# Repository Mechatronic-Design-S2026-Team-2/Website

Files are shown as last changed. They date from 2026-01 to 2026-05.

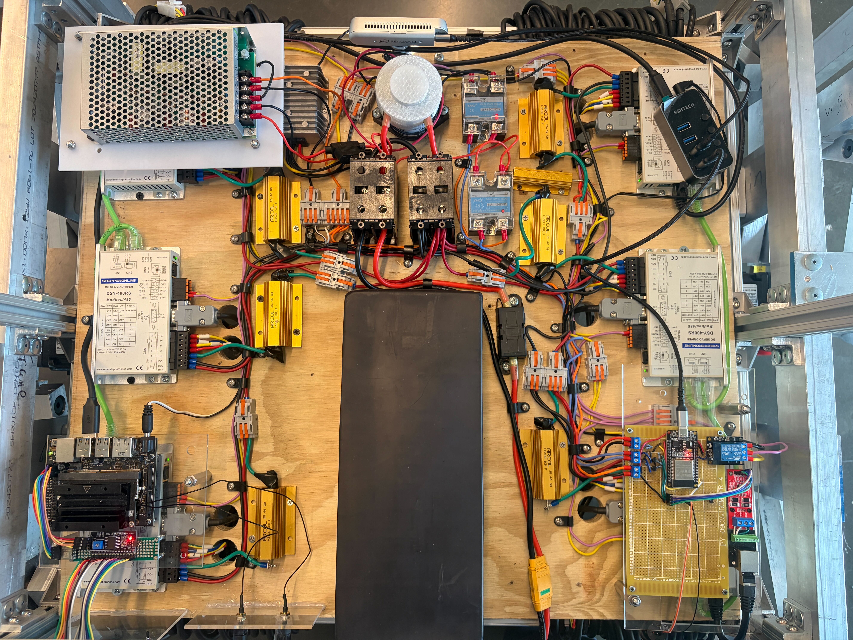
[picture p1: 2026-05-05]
docs/assets/hardware/full_circuit_mainboard.jpg

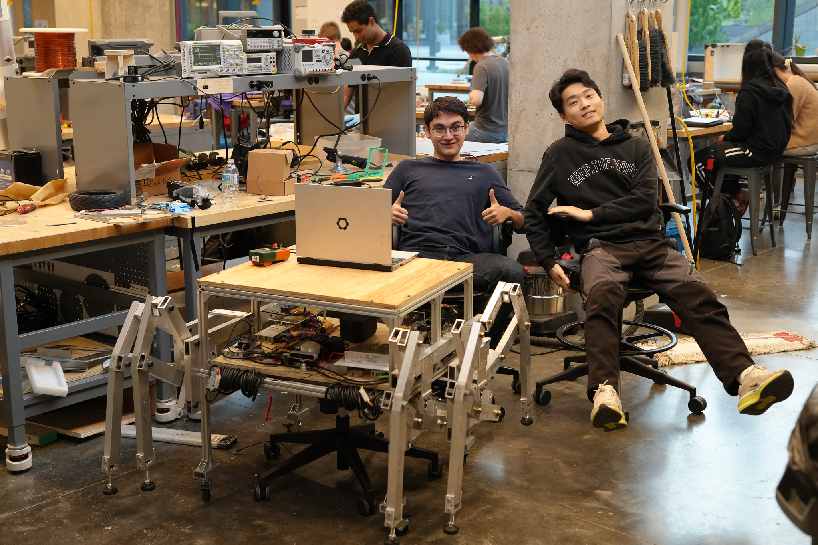
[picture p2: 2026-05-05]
docs/assets/hardware/working_on_bot.jpg

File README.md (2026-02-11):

# Team 2 — Dance Robot Project Website 

This repo is a **GitHub Pages** site for the Mechatronic Design project website.

## What’s included
- Required top-level pages: Problem, Design, Implementation, Performance, Management, Media, Team, Documents
- A Documents “workbook” area with folders for brainstorming, schematics, testing, software, presentations, ILRs
- Project management templates: schedule, parts list, issues log (CSV)

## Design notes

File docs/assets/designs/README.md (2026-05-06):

# CAD and design exports

Existing GLB files are used by the site. Add final exports here:

- klann_final.glb
- v5_final_assembly.glb
- linkage_schematic.pdf

The linkage drawing should be exported as PDF for browser-friendly viewing and downloading. Keep the original DWG in the repo as a source file if useful, but the website now references the PDF.

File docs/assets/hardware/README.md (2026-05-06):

# Hardware photos

Place final hardware, cover, chassis/electronics, and electrical integration photos here:

- full_circuit_mainboard.jpg
- full_assembly_no_lid.jpg
- chassis_and_early_board.jpg
- front_final_cover.JPG
- angled_final_cover.JPG
- mainboard_in_progress.jpg
- pcb_mount_prototype.jpg
- working_on_bot.jpg
- debugging.jpg

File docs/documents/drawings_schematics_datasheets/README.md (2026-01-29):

[Home](index.md) •
[Problem](problem.md) •
[Design](design.md) •
[Implementation](implementation.md) •
[Performance](performance.md) •
[Project Management](management.md) •
[Media](media.md) •
[Documents](documents.md) •
[Team](team.md)

# Drawings / Schematics / Datasheets

Store PDFs/images of CAD, wiring diagrams, schematics, and relevant datasheet excerpts.

## Suggested structure
- `YYYY-MM-DD_<short_title>.pdf` or `.md`
- Keep files small; link to external storage for huge videos/logs.

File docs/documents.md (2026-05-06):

---
title: "Documents (Workbook)"
---

{% include nav.html %}
{% include page-assets.html cards=true %}

<div class="t2-card">
  <h2>Documents</h2>
  <p>
    Core reports and presentations are embedded here so the website can serve as a self-contained project workbook. The final report is the most accurate source for the as-built mechanical/electrical design and budget. The mapping report is the most detailed source for the Jetson/ESP32/RS485/kinematic-odometry software stack.
  </p>
</div>

{% include pdf-card.html
   title="Final Report"
   pdf="/assets/pdfs/final_report.pdf"
   subtitle="As-built class-final report: final design, system evaluation, budget, risks, and future work."
   height="82vh" %}

{% include pdf-card.html
   title="Resource-Constrained Odometry, Localization, and Mapping Report"
   pdf="/assets/pdfs/mapping_report.pdf"
   subtitle="Detailed software paper covering raw encoder timing, Klann kinematic odometry, ORB-SLAM2 CUDA, slam_toolbox, Nav2, and fusion."
   height="82vh" %}

{% include pdf-card.html
   title="Mapping Proposal"
   pdf="/assets/pdfs/Mapping_proposal.pdf"
   subtitle="Original staged plan for onboard odometry, localization, mapping, and embedded feasibility evaluation."
   height="72vh" %}

{% include pdf-card.html
   title="Design Proposal"
   pdf="/assets/pdfs/design-proposal.pdf"
   subtitle="Initial mechanical/electrical/software design proposal, retained for design history and trade-study context."
   height="72vh" %}

{% include pdf-card.html
   title="Design Proposal Presentation"
   pdf="/assets/pdfs/design-proposal-presentation.pdf"
   subtitle="Proposal slide deck."
   height="72vh" %}

{% include pdf-card.html
   title="Mapping Presentation"
   pdf="/assets/pdfs/mapping_presentation.pdf"
   subtitle="Localization and mapping presentation deck."
   height="72vh" %}

{% include pdf-card.html
   title="Midsemester Presentation"
   pdf="/assets/pdfs/midsemester_presentation.pdf"
   subtitle="Midsemester status and design evolution."
   height="72vh" %}

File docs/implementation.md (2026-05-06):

---
title: "System Implementation"
---

{% include nav.html %}
{% include page-assets.html cards=true implementation=true media_gallery=true model_viewer=true svg_diagram=true carousel=true %}

<div class="t2-card" id="implementation-status">
  <h2>Implementation</h2>
  <p class="t2-sub">As-built hardware, firmware, Jetson deployment, ROS 2 package integration, and operator workflow for the class-final robot.</p>
  <p>
    The final robot is a distributed system with one ESP32 responsible for power sequencing and motor-bus I/O, a Jetson Nano host responsible for the RealSense/ORB-SLAM2 CUDA process, and a ROS 2 Jazzy container responsible for state estimation, visualization, mapping, navigation, operator controls, and micro-ROS integration.
  </p>
  <div class="t2-links">
    <a class="t2-linkbtn" href="#hardware-build">Hardware build</a>
    <a class="t2-linkbtn" href="#firmware-runtime">ESP32 runtime</a>
    <a class="t2-linkbtn" href="#jetson-deployment">Jetson deployment</a>
    <a class="t2-linkbtn" href="#ros-packages">ROS 2 packages</a>
    <a class="t2-linkbtn" href="#integration-flow">Integration flow</a>
    <a class="t2-linkbtn" href="#operatorui">Operator UI</a>
  </div>
</div>

<div class="t2-card" id="hardware-build">
  <h2>Hardware Build</h2>
  <p>
    The build sequence progressed from raw aluminum stock through chassis fabrication, linkage fabrication, electronics mounting, and final assembly. The ordered carousel shows the manufacturing path rather than isolated hero photos, making the final hardware easier to relate to the design evolution and budget.
  </p>
  {% include carousel.html key="hardware_build_sequence" %}
</div>

<div class="t2-card" id="firmware-runtime">
  <h2>ESP32 Firmware Runtime</h2>
  <p>
    The ESP-IDF firmware keeps startup and runtime deliberately separate. Startup uses the slower, proven configuration path for precharge, contactor closure, servo enable, motor mode setup, torque/current limiting, speed limits, acceleration/deceleration settings, and initial zero-speed commands. Runtime then switches to short RS485 helpers for changed RPM writes and encoder reads.
  </p>
  {% include carousel.html key="esp_runtime_sequence" %}
  <div class="t2-table-wrap">
    <table class="t2-table">
      <thead><tr><th>Runtime feature</th><th>Final behavior</th><th>Reason</th></tr></thead>
      <tbody>
        <tr><td>RPM command writes</td><td>Changed-only writes by default; stop commands can preempt between RS485 transactions.</td><td>Avoids wasting the 115200 baud bus rewriting unchanged speeds.</td></tr>
        <tr><td>Encoder telemetry</td><td>Strict six-drive raw encoder sweep, then compact micro-ROS odometry publication.</td><td>Keeps all legs observable and avoids odd/even polling starvation.</td></tr>
        <tr><td>Phase semantics</td><td>ESP publishes raw 17-bit single-turn encoder counts rather than final output phase.</td><td>The 50:1 gearbox causes many motor-encoder wraps per crank revolution, so continuous phase belongs on the Jetson observer.</td></tr>
        <tr><td>Timing fields</td><td>Command sequence, receive, apply, poll, and publish timestamps are included.</td><td>Host-side estimation can reason about command propagation and measurement age.</td></tr>
      </tbody>
    </table>
  </div>
  <p class="t2-note">
    Final deployed runtime parameters from the mapping report include RS485 motor bus at 115200 baud, micro-ROS UART at 921600 baud, one runtime transaction attempt, a 25 ms six-drive encoder sweep target, a 50 ms odometry publish period, 131072 encoder counts per motor revolution, 50:1 gearbox ratio, and 250 ms / 250 ms motor driver acceleration/deceleration settings.
  </p>
</div>

<div class="t2-card" id="jetson-deployment">
  <h2>Jetson Deployment</h2>
  <p>
    The Jetson Nano deployment is split because the project needs both host-native GPU/RealSense access and a modern ROS 2 stack. ORB-SLAM2 CUDA, RealSense, CUDA/OpenCV, and Pangolin run directly on the Jetson host. ROS 2 Jazzy runs in a Docker container with host networking and the project workspace mounted for development.
  </p>
  {% include carousel.html key="jetson_deployment_sequence" %}
  <details class="t2-acc" open>
    <summary><h3>Host-native process</h3></summary>
    <div class="t2-acc-body">
      <p>
        The RealSense executable acquires aligned RGB-D frames from the D415, uses meter-scale depth, skips malformed frames, hardens startup/retry behavior, and emits UDP products to <code>127.0.0.1:5005</code> for the ROS container.
      </p>
    </div>
  </details>
  <details class="t2-acc">
    <summary><h3>Container role</h3></summary>
    <div class="t2-acc-body">
      <p>
        The container runs the hardware observers, Klann geometry model, weighted odometry fusion, ORB UDP bridge, slam_toolbox, Nav2, RViz, operator interface, and micro-ROS agent integration. Host networking keeps UDP, TF, and ROS discovery simple on the robot.
      </p>
    </div>
  </details>
</div>

<div class="t2-card" id="ros-packages">
  <h2>ROS 2 Packages</h2>
  <p>
    The ROS workspace is organized so low-level messages stay compact and high-level nodes reconstruct the robot state before planners see it.
  </p>
  <div class="t2-table-wrap">
    <table class="t2-table">
      <thead><tr><th>Package</th><th>Implemented role</th><th>Representative topics / outputs</th></tr></thead>
      <tbody>
        <tr><td><code>dsy_motor_msgs</code></td><td>ESP bridge messages for motor RPM command and six-drive raw encoder/timing telemetry.</td><td><code>/motor_rpm_cmd</code>, <code>/motor_output_odom</code></td></tr>
        <tr><td><code>hexapod_control_interfaces</code></td><td>Robot-level leg phase, motor state, actuation, and body-state messages.</td><td><code>/hexapod/phase_cmd</code>, <code>/hexapod/motor_state</code>, <code>/hexapod/body_state</code></td></tr>
        <tr><td><code>hexapod_hardware_cpp</code></td><td>Motor-state aggregation, encoder unwrap, measured Klann model, body-kinematic odometry, weighted fusion, WT901 interface, startup pose, LCD/status, and RViz markers.</td><td><code>/hexapod/kinematic_odom</code>, <code>/hexapod/fused_odom</code>, <code>/odom</code>, <code>/klann_markers</code></td></tr>
        <tr><td><code>hexapod_nav_cpp</code></td><td>Planner-facing phase prediction and phase command generation, including final phase wrapping and mirror/direction correction.</td><td>Phase targets bounded to <code>[-pi, pi]</code></td></tr>
        <tr><td><code>hexapod_orbslam_udp_bridge</code></td><td>UDP bridge from host-native ORB-SLAM2 CUDA to ROS odometry, sparse points, and depth-derived virtual scan.</td><td><code>/hexapod/orbslam_odom</code>, <code>/orbslam/map_points</code>, <code>/scan</code></td></tr>
        <tr><td><code>hexapod_operator_interface</code></td><td>Browser GUI for teleop, map viewing, waypoint goals, velocity limits, map save/load, and software e-stop.</td><td><code>/hexapod/cmd_vel_selected</code>, Nav2 goals, map service calls</td></tr>
      </tbody>
    </table>
  </div>
</div>

<div class="t2-card" id="integration-flow">
  <h2>Integration Flow</h2>
  <p>
    Final bring-up combines power sequencing, encoder telemetry, host SLAM, ROS 2 mapping/control, and operator commands in a repeatable order.
  </p>
  {% include carousel.html key="integration_flow_sequence" %}
  <ol>
    <li>Precharge the 52 V bus, close the contactor, and enable the servo drivers only after voltage and timing checks pass.</li>
    <li>Validate RS485 command writes and six-drive raw encoder telemetry before commanding gait motion.</li>
    <li>Start the host-native ORB-SLAM2 CUDA/RealSense process and confirm UDP pose, points, and virtual scan output.</li>
    <li>Launch the ROS 2 container stack, verify TF/scale alignment in RViz, then enable teleop or waypoint control.</li>
  </ol>
</div>

<div class="t2-card" id="operatorui">
  <h2>Operator Interface</h2>
  <p>
    The operator interface is a browser page served from the ROS 2 side of the Jetson. It exposes teleop, velocity limits, map visualization, waypoint placement, map save/load, status display, and a software stop mode so testing can be performed without manually invoking every ROS command.
  </p>
  <p>
    The final workflow keeps the laptop as a remote terminal and visualization/control client while the robot carries the Jetson, ESP32, battery, motor drivers, and sensors onboard.
  </p>
</div>

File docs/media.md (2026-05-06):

---
title: "Media"
---

{% include nav.html %}
{% include page-assets.html cards=true media_gallery=true model_viewer=true %}

<div class="t2-card">
  <h2>Media</h2>
  <p>
    This page collects final build, fabrication, electrical integration, software visualization, simulation verification, CAD/modeling, and robot-motion media. WebM clips are presented as silent looping animations; the single-linkage MP4 is also rendered as an inline looping mechanism animation.
  </p>
  
</div>

<div class="t2-card">
  {% include asset-gallery.html key="team_picture" %}
</div>

<div class="t2-card">
  {% include asset-gallery.html key="build_photos" %}
</div>

<div class="t2-card">
  {% include asset-gallery.html key="fabrication" %}
</div>

<div class="t2-card">
  {% include asset-gallery.html key="circuit_photos" %}
</div>

<div class="t2-card">
  {% include asset-gallery.html key="software_visuals" %}
</div>

<div class="t2-card">
  {% include asset-gallery.html key="simulation_media" %}
</div>

<div class="t2-card">
  {% include asset-gallery.html key="videos" %}
</div>

<div class="t2-card">
  <h2>Fusion 360 CAD Embeds and Local Fallbacks</h2>
  <p>
    Fusion 360 embeds are the primary detailed CAD views for the schematic, final assembly, final Klann linkage, and later assembly iterations. Each card also exposes the local PDF or GLB fallback so the site still has a usable static artifact if Autodesk sharing is unavailable. Version 1 remains a local GLB viewer because no Fusion embed is configured for it.
  </p>
  <p class="t2-note">
    To force a local fallback, set <code>use_fallback: true</code> on that item in <code>docs/_data/media_assets.yml</code>. Leave it <code>false</code> to use the Fusion 360 iframe by default.
  </p>
  {% include asset-gallery.html key="fusion_cad" %}
</div>

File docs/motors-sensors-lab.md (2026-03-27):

---
title: "Motors/Sensors Lab"
---

{% include nav.html %}
{% include page-assets.html cards=true carousel=true lab=true codebox=true %}

<div class="t2-card">
  <h2>Lab highlights</h2>

  {% include lab-carousel.html %}
</div>

<div class="t2-card">
  <h2>KiCad schematic</h2>
  {% include kicad-embed.html
     wrap="false"
     repo="Mechatronic-Design-S2026-Team-2/Website"
     ref="main"
     path="docs/assets/designs/sensor_motor_lab/18578sensor.kicad_sch"
  %}
</div>

<div class="t2-card">
  <h2>Mainfile</h2>

  {% include repo-button.html
   label="Sensors/Motors Lab repo"
   href="https://github.com/Mechatronic-Design-S2026-Team-2/Sensors-Motors-Lab" %}

  {% include lab-code.html wrap="false" %}
</div>

<div class="t2-card" id="ilrs">
  <h2>ILRs</h2>
  <div class="t2-sub">In-lab reports (PDFs). Expand each dropdown to view.</div>

  {% include ilr-dropdowns.html %}
</div>

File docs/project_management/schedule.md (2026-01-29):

[Home](index.md) •
[Problem](problem.md) •
[Design](design.md) •
[Implementation](implementation.md) •
[Performance](performance.md) •
[Project Management](management.md) •
[Media](media.md) •
[Documents](documents.md) •
[Team](team.md)

# Schedule (Template)

Add your Gantt chart image here **or** maintain milestones below.

## Milestones
- Week X: Locomotion prototype v1
- Week X: Sensor bring-up (camera/IMU/encoders)
- Week X: Basic state estimation
- Week X: Point-to-point navigation demo
- Week X: Obstacle stop behavior
- Week X: Full system integration + performance testing

## Weekly plan
| Week | Focus | Owner(s) | Deliverable |
|---|---|---|---|
| 1 | Setup repo + website + bring-up | TBD | Site live + dev environment |
| 2 | TBD | TBD | TBD |

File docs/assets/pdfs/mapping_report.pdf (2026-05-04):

## Resource-Constrained Odometry, Localization, and Mapping on a Human-Carrying Hexapod

Daniel González Lázaro

Abstract— This report summarizes the final implemented odometry, localization, and mapping stack for a human-carrying Klann-linkage hexapod built around a Jetson Nano, a RealSense D415, six RS485 servo motor drivers with 17-bit motor encoders, 50:1 planetary gearboxes, and an ESP32 micro-ROS bridge. telemetry, a ROS 2 C++ motor-state observer that unwraps single-turn 17-bit motor encoders through the 50:1 gearbox, a Klann-body kinematic odometry estimator, a planar weighted odometry fusion node, and an ORB-SLAM2 CUDA RealSense UDP bridge that exports pose, map points, and a lightweight virtual scan for slam_toolbox and Nav2 occupancy-grid navigation. The biggest embedded issues were not the high-level ROS interfaces, but the RS485 transaction schedule, the semantics of the servomotor encoder, and the limited reliability of the ESP32 ADC channels for foot-contact sensing. The final system produced teleoperated straight-line odometry results within the 6 tolerance required by the AXIS Dance Company collaboration, although the kinematic scale remains a tunable calibration parameter. The resulting architecture treats RGB-D SLAM as the primary mapping/localization source and treats body-kinematic odometry as a fallback and fusion component when visual tracking is degraded or the camera is partially occluded by riders or nearby people.

I. INTRODUCTION AND FINAL SYSTEM CONTEXT

The target platform is an assistive mobility device for AXIS Dance Company that must transport a rider without wheels as the primary locomotor, fit within a 5 ft by 5 ft footprint, carry up to a 170 lb rider while keeping the total mass of the system below 150 lb, and navigate to a designated point in a performance stage within 6 in in 1 min [1]. The final demonstrations also require straight and curvilinear forward and backward traversals over 10 feet in a test area of 10 feet by 10 feet, with penalties for path deviation and manual intervention [1]. These requirements make odometry and mapping central to the project rather than optional instrumentation.
The final implementation uses a staged estimator. The RealSense D415 and ORB-SLAM2 CUDA process provide exteroceptive motion and sparse mapping; the ROS 2 UDP bridge converts this output into ROS odometry, point-cloud visualization, and a virtual planar scan for slam_toolbox occupancy mapping. That occupancy grid is included for the Nav2 navigation stack, not merely for visualization: it is the grid map on which future autonomous goal selection,

This implementation was a component of Spring 2026 mechatronic design’s team 2, and our human-carrying hexapod project. Other members of team 2 are: Yechen Zheng, Hongfei Liu, and Hongru Liu
Project website: https://mechatronic-design-s2026-team-2.github.io/Website/. (https://mechatronic-design-s2026-team-2.github.io/Website/) Code repository: https://github.com/Mechatronic-Design-S2026-Team-2/Design. (https://github.com/Mechatronic-Design-S2026-Team-2/Design)

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

II. FINAL EMBEDDED MOTOR AND ENCODER
IMPLEMENTATION
The | final | ESP32 | firmware | accepts
dsy_motor_msgs/MotorRpmArray
on | /motor_rpm_cmd | and | publishes
dsy_motor_msgs/MotorOutputOdometryArray
on /motor_output_odom. The message package name is historical; the relevant hardware behavior is that one ESP32 controls six RS485 servo drives. The six-element command and odometry vectors remain in physical ESP bus order [rb, rm, rf, lf, lm, lb], which follows the physical wire distance from the ESP32 to the motor drivers on the RS485 daisy chain, from closest to farthest. On the host, this is remapped to the canonical kinematic model
order [rf, rm, rb, lf, lm, lb] through [2, 1,

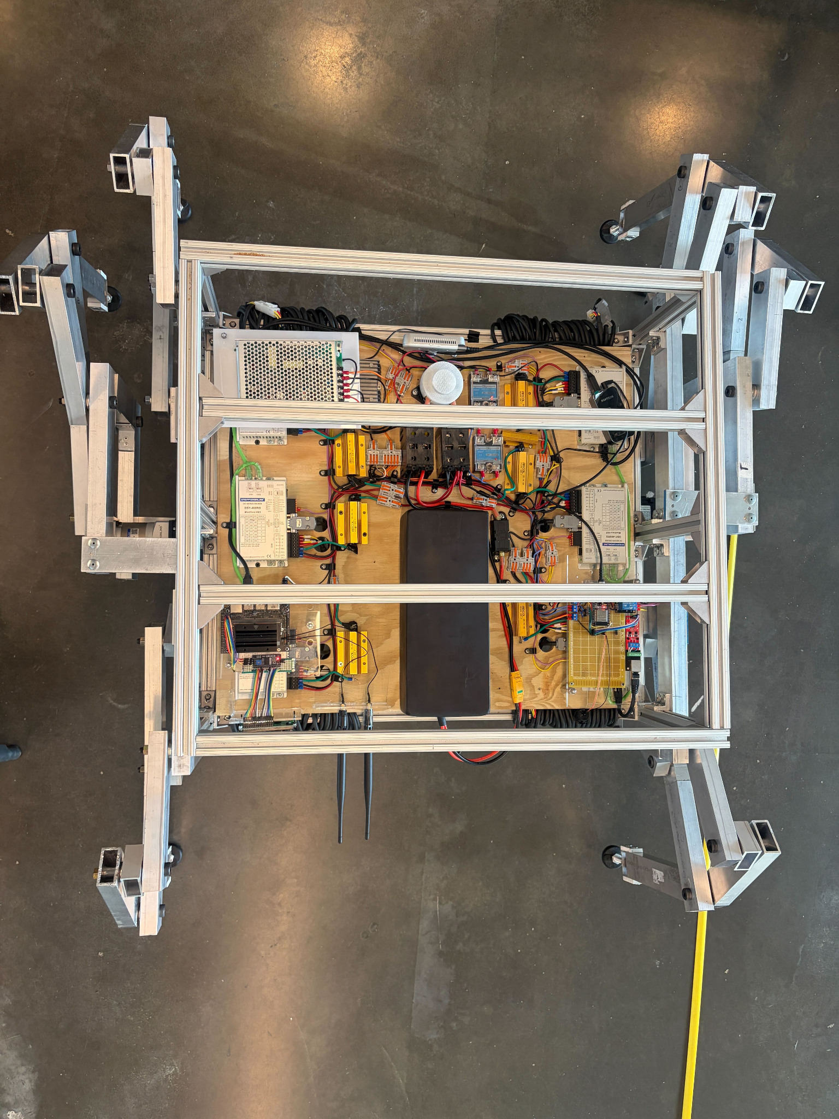
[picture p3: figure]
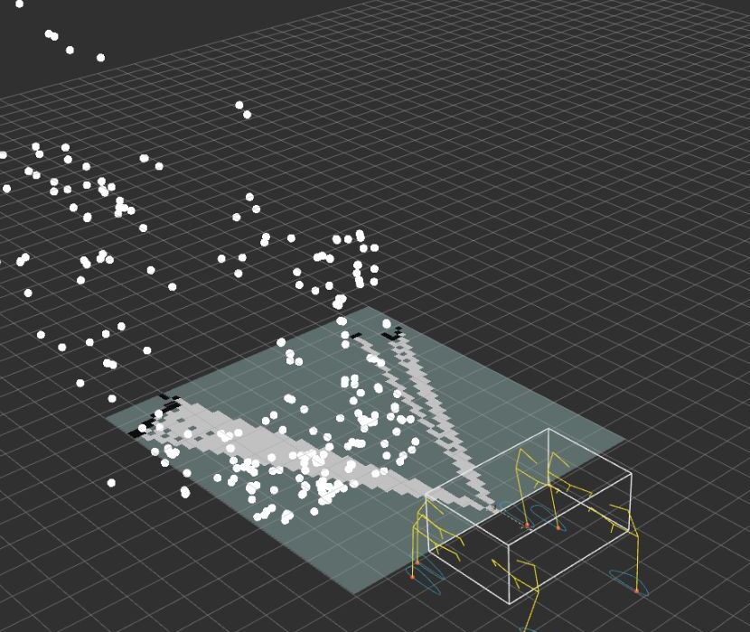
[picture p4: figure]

(a) final top-view hardware layout | (b) merged RViz view with skeleton, ORB points, and occupancy/grid products

Fig. 1. Final physical and mapping configuration. The top-view chassis photograph shows the distributed electronics, motor-driver layout, RS485 wiring context, and six linkage modules. The merged visualization shows the robot skeleton, sparse visual map products, and the grid/scan products used to validate scale and transform consistency before using the map for Nav2 navigation.

0, 3, 4, 5]. This separation was important because
bus-debugging tools, direct teleoperation tests, and firmware
logs are easiest to interpret in cable order, while the Klann model and controller need a consistent front/middle/back order for each side.

The final embedded code deliberately separates startup configuration from runtime communication. Startup retains the slower verified path for motor-driver configuration, including control mode, torque/current limiting, speed command source, speed limits, acceleration/deceleration parameters, and enable sequencing. Runtime uses short RS485 helpers for changed RPM writes and encoder reads. This reduced risk because earlier event-driven versions changed too much of the bringup code at the same time as the runtime path. Reusing the proven power/enable sequence also avoided failures where the active-low servo-enable relay briefly left the drives disabled or caused inconsistent drive readiness.

The runtime message includes timing fields added specifically for delay-aware host estimation: command_seq,
last_cmd_seq, | esp_cmd_rx_time_us,
esp_apply_complete_time_us,
esp_poll_complete_time_us, | and
esp_publish_time_us. | These | fields | allow | the
ROS 2 observer to estimate command receive-to-apply time, apply-to-poll time, poll-to-publish time, and the external transport delay between the host and ESP32. The estimator uses these values to compensate phase for measurement age

TABLE I

FINAL DEPLOYED RUNTIME PARAMETERS USED BY THE SOFTWARE

STACK.

Parameter | Final value
RS485 motor bus baud rate | 115200
micro-ROS UART baud rate | 921600
RS485 runtime response timeout | 50 ms
RS485 runtime turnaround delay | 2 ms
Runtime transaction attempts | 1
Six-drive encoder sweep period | 25 ms
Odometry publish period | 50 ms
Encoder counts per motor rev | 131072
Gearbox ratio | 50:1
Driver accel/decel time | 250 ms / 250 ms
Kinematic XY scale | 2.1786
ORB/scan scale | 1.382
Virtual scan range | 0.45–3.0 m
Camera X offset from base_link | 0.2794 m

and future command-application delay rather than treating every motor sample as instantaneous.
The motor command path uses changed-only writes by default. Once a drive has accepted a commanded RPM, that RPM is not resent unless the value changes or a periodic resend mode is explicitly enabled. This behavior matters on a six-drive 115200 baud bus. Continuously rewriting unchanged commands consumes the same bus capacity needed to poll encoders, and it can make the odometry stream appear frozen even though the micro-ROS topic itself is still publishing.
The key firmware change is that the ESP32 no longer attempts to compute output-shaft phase in the embedded runtime path. Instead, output_phase_rad[] is reused, for compatibility with the existing message definition, to carry raw P18.32/P18.33 single-turn encoder counts. For the installed M17S 17-bit encoders, the raw range is 0 to 131071 counts per motor revolution, which fits exactly in the float field used by the current message. The host computes continuous phase by unwrapping the modulo count, applying the 50:1 gearbox ratio, applying the physical-to-model sign convention, and subtracting the startup reference. This moved the ambiguous part of the estimate from the memory- and timing-constrained ESP32 into the ROS 2 observer, where command history and model constraints are available.
The code finally treats P18.32/P18.33 as a single-round absolute encoder value and leaves P18.34 out of the odometry path. Earlier debugging considered feedback pulse counters and multi-round monitor registers, but the reliable source for the installed M17S encoder was the modulo single-turn value. The RS485 driver also includes a word-order guard for this 32-bit monitor value: if the high-word-first interpretation is outside the expected 17-bit range but the low-word-first interpretation is valid, the valid ordering is selected. This avoids silently accepting a nonsensical encoder count caused by Modbus word-order differences.
For a raw count ck, counts per motor revolution N = 131072, and gearbox ratio G = 50, the host observer estimates output phase as

ϕk = si

2π
NGCˆ
k + ϕ0i
, | (1)

where si

is the physical-to-model sign for leg i, ϕ0i | is
the configured phase offset, and Cˆ
k is the continuous unwrapped motor-count estimate. The observer predicts Cˆ
| k
from the latest accepted command and the configured acceleration/deceleration time, then corrects it toward the raw encoder measurement by choosing the nearest plausible wrap. A bounded innovation prevents a single stale or misread RS485 sample from jumping the phase by multiple motor turns.
This design also makes explicit that the encoder is a single-turn motor encoder, not a multi-turn output encoder. A full output-shaft revolution corresponds to 50 motor revolutions, so the raw motor encoder wraps many times during one output cycle. The host can infer the correct wrap count only if the raw count is polled often enough that the count change between accepted samples remains below the half-revolution ambiguity limit, or if commanded RPM and acceleration constraints are used to choose the nearest plausible wrap. The final observer therefore combines raw-count measurements with a ramp-limited command prediction. It ignores unchanged raw samples during commanded motion when the ESP has merely republished a cached six-element vector while the RS485 worker has not yet refreshed that drive. The physical phase zero was set manually. Before tests, each linkage output crank was positioned to point straight down from the motor output shaft so that all six legs began from the same mechanical phase. In software, this corresponds to zero phase offsets in the deployed configuration. This manual setup made phase visualization, tripod timing, and straight-line odometry calibration much easier because startup phase differences were dominated by actual encoder readings rather than arbitrary assembly offsets.

III. RS485 TIMING ISSUES AND FINAL SCHEDULER
The most important embedded problem was RS485 bus scheduling. The system has one ESP32 talking to six RS485 servo motor drivers over a 115200 baud bus. Every transaction requires bus turnaround time, response timeout handling, and drive-specific acknowledgement. Early runtime designs either wrote repeated unchanged RPM commands, interleaved reads and writes too aggressively, or polled only one drive per publish cycle. Those versions could appear responsive for one tripod group while starving or freezing the other group, especially when commands were updated faster than the bus could complete the read/write sequence. The observed failure modes were consistent with scheduler starvation rather than ROS topic failure. Some versions produced a latching tripod update pattern: one set of legs would update after one unique command, then the opposite set would update only after another unique command. Other versions updated only one phase per published message, which made the ROS topic appear alive but too sparse to support continuous crank unwrapping. Increasing transaction retries could make more values update, but it also increased bus occupancy and stop latency. The final design therefore focused on deterministic coverage rather than brute-force retrying.
The final firmware separates startup configuration from runtime communication. Startup still uses the slower, verified drive configuration path for mode setup, torque limits, enable behavior, speed command source, speed limits, and acceleration/deceleration parameters. Runtime uses shorter RS485 read/write helpers with menuconfig-exposed timing values. The final defaults include a 115200 baud RS485 bus, 921600 baud micro-ROS UART, a 50 ms runtime response timeout, a 2 ms runtime turnaround delay, and one runtime transaction attempt. These values were chosen to avoid indefinite pending-write behavior while keeping operator stop latency acceptable.
The runtime worker is a strict six-drive encoder sweep state machine. A new sweep starts at the configured sweep period, reads drive 1 through drive 6 without artificially spacing the reads by the main worker loop delay, and then waits until the next sweep period. A pending all-zero RPM command preempts the sweep between RS485 transactions, so a stop command is applied before additional noncritical encoder reads. A pending nonzero command is applied when no sweep is active. Unchanged RPM values are not rewritten unless an explicit resend mode is enabled, reducing bus pressure. This scheduler was the major change that made the firmware practical: it preserves full six-drive odometry coverage while preventing the bus from being consumed by continuous single-drive polling.

The remaining timing caveat is inherent to single-turn encoders. Higher motor RPM reduces the time available before one motor-encoder wrap becomes ambiguous. At 1000 motor rpm, a motor revolution lasts about 60 ms; with a 50:1 gearbox, the output is only 20 rpm, but the encoder still wraps every motor revolution. Therefore the useful odometry limit is not only the mechanical output speed; it is the RS485 polling rate relative to motor-encoder wrap rate. The final host estimator mitigates this using command prediction, acceleration/deceleration timing, and an innovation limit, but no software observer can fully recover a wrap count if the bus misses too many consecutive raw samples during highspeed motion.

IV. HOST-SIDE PHASE, BODY-KINEMATIC ODOMETRY, AND FUSION

The ROS 2 C++ workspace implements the host-
side | estimator | in | hexapod_hardware_cpp. | The
motor_state_aggregator_node | subscribes
to | /motor_output_odom | and | to | direct
/motor_rpm_cmd | commands. | It | keeps | command
sequence history, ESP-domain timestamps, and host receive times to estimate command propagation delay. It then unwraps the raw single-turn encoder count into continuous motor counts, converts counts to output crank phase using 131072 counts per motor revolution and the 50:1 gearbox, and publishes /hexapod/motor_state. Phase velocity is computed as a weighted blend of measured phase difference and command-predicted phase rate.
The body_state_estimator_node evaluates the
measured Klann linkage model for each leg. For each stance leg, the no-slip constraint is that body translational velocity plus yaw-induced foot velocity plus the foot velocity from the linkage should be approximately zero. The node solves a weighted least-squares problem for planar body twist:
1 0 −piy

0 1 pix

vx
vy
ωz
- = −
p˙ix

p˙iy
, | (2)

for all legs whose stance confidence exceeds the configured threshold. At least three stance legs are required before the estimate is trusted. This matches the physical intent of the alternating tripod gait: while three feet are supporting the robot, their foot velocities constrain body motion.
The kinematic model uses the measured linkage YAML rather than hard-coded foot trajectories. This is important because a Klann leg is not a simple wheel or crank-slider. One rotating output crank drives a set of bars that produce an approximate walking foot path: part of the cycle is a low, nearly horizontal stance stroke that can push against the ground, and the rest is a lifted return stroke. The odometry problem is therefore to infer body motion from six measured crank phases and the modeled velocity of each foot tip, not from wheel radius or direct linear encoders.
Each leg is solved in its local sagittal plane. The YAML describes the motor-shaft location, fixed top and bottom pivots, crank radius, link lengths, rigid angle constraints, unknown joint names, and foot point. For a given crank phase, the solver first places the crank tip and then solves the nonlinear linkage constraints for the remaining joints. The implementation uses a damped least-squares solve over distance residuals and angle residuals, with the previous phase’s solution reused as the next initial guess. The local foot coordinate is then mounted into the robot body frame with the measured shaft position and lateral offset, giving the stance-foot position used by the body-twist solve.
The same geometry is shared by the visualizer, the bodystate estimator, and the phase controller. For deployment, however, repeatedly solving the nonlinear linkage at runtime is undesirable on the Jetson Nano because SLAM, virtualscan generation, micro-ROS, TF publication, and visualization are already competing for CPU. The workspace therefore includes a configurable lookup-table generator that precomputes each leg’s phase-to-foot trajectory on a faster computer. The table is indexed by output-crank phase, not by the raw motor encoder count. This distinction is important: the encoder has 131072 counts for one motor-input revolution, while the 50:1 gearbox means one output-crank revolution spans 6553600 possible motor-count states. A lookup table that exactly matched the encoder-derived output-phase lattice would therefore be unnecessarily large and would not improve accuracy beyond the mechanical model, backlash, foot compliance, and slip errors. The practical table resolution should be selected from interpolation error in the smooth Klann trajectory rather than from the encoder’s single-turn count. For this project, 8192 to 16384 samples per output-crank revolution is the appropriate production range, with larger tables such as 32768 or 131072 samples useful only for offline validation of interpolation error and stance-window boundaries. The generator writes one compact binary .klut file per leg plus a patched YAML file that points the runtime system at those tables.
Each lookup sample stores local foot position, numerical derivatives with respect to output-crank phase, and stance confidence. The derivative is used to convert measured phase velocity into foot-tip velocity without running a second linkage solve. Stance confidence combines the configured stance phase window with geometric information from the trajectory: low foot height and small vertical motion are weighted more heavily than lifted return motion. Runtime evaluation then becomes interpolation between adjacent table entries. This converts the body odometry path from an iterative geometry solve into a deterministic table lookup, which is better suited to Nano-class compute and makes the estimator’s timing more predictable. The interpolation error can be bounded by regenerating the table at multiple resolutions and comparing the interpolated foot position and derivative against the direct nonlinear solve; that check is a better criterion than matching the input encoder resolution. The host model includes delay compensation but is not a full Kalman filter. The motor-state message carries estimated measurement age and future command-application delay. The body estimator advances each measured phase by the estimated measurement age times the latest phase velocity

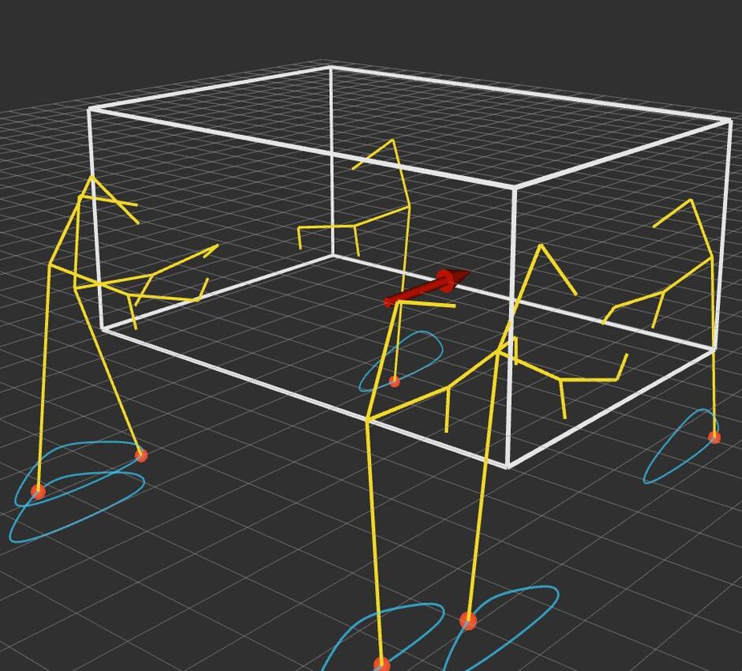
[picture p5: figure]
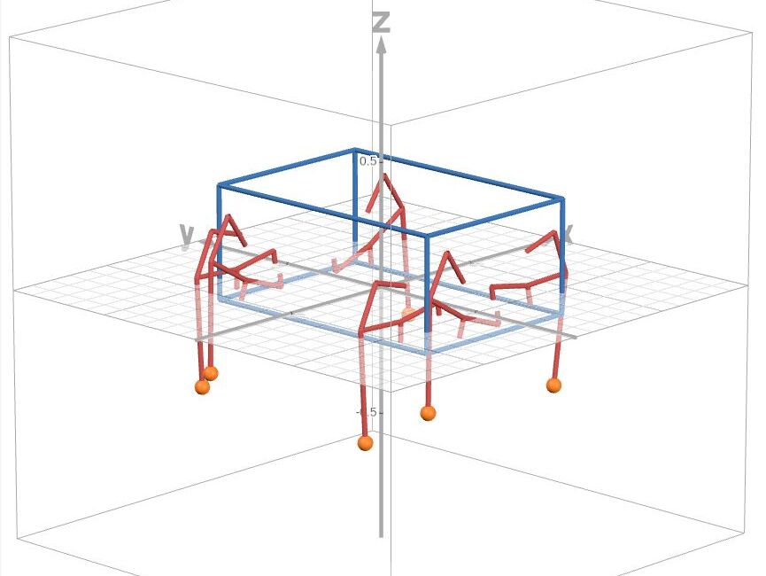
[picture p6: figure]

(a) ROS/RViz skeleton and modeled foot paths | (b) Desmos 3D linkage model used for geometry validation

Fig. 2. Klann-linkage modeling views. The runtime estimator uses the same linkage geometry represented in the ROS visualizer and the public Desmos model. The Desmos model is available at https://www.desmos.com/3d/18nie5ecgp.

before evaluating the linkage model. This command-preview
approach was simpler to debug than a per-leg EKF while
the RS485 timing and encoder semantics were still being stabilized. A per-leg EKF remains a reasonable follow-up. Such a filter would estimate each leg’s continuous motor count, velocity, possibly acceleration or driver-latency bias, and wrap index using commanded RPM as the process input and the modulo 17-bit encoder count as the measurement. Its benefits would be explicit uncertainty per leg, smoother behavior through missed RS485 samples, principled rejection of stale or misordered reads, and a cleaner way to fuse FSR contact probability when the analog hardware is stabilized. The tradeoff is tuning and debugging cost: process noise must represent driver acceleration limits, RS485 latency, and contact/slip uncertainty; the discrete wrap ambiguity still cannot be recovered if polling violates the half-motorrevolution limit for too long; and an EKF can hide timing bugs that are easier to diagnose with the deterministic unwrap currently used. Since the deterministic observer already met the straight-line tolerance, the EKF should be treated as a reliability and uncertainty-improvement path rather than a required class-final component.

After straight-line testing, the final code includes a kinematic mirror and axis-scale calibration. In the 73 in test, the raw kinematic estimate before the final scale adjustment reported approximately 0.851 m of forward motion for a physical 1.854 m displacement. The final configuration there-
fore enables mirror_kinematics_across_y_axis and applies body_twist_axis_scale: [2.1786,
2.1786, 1.0]. This produced teleoperated straight-line odometry within the 6 in task tolerance, but the scale should still be treated as an empirical calibration parameter. A larger data set with forward, backward, and turning trials should be used before treating the coefficient as final.

The weighted_odom_fusion_node publishes the
generic /odom and the odom -> base_link transform. It can fuse kinematic odometry, IMU data, and ORB-SLAM odometry. In the mapping configuration used here, the node forces the pose planar, keeps roll and pitch weights at zero, and fuses ORB-SLAM as a relative planar odometry source. The first ORB pose becomes the local origin so that a large absolute ORB yaw at startup does not rotate the robot skeleton or the occupancy grid. This makes the leg-kinematic odometry useful both as a fallback when ORB tracking is lost and as a fusion component when ORB-SLAM is available but intermittently noisy.
The final TF ownership is explicit. slam_toolbox
owns | map -> odom. | The | weighted | fusion | node
owns | odom -> base_link. | The | ORB-SLAM
UDP | bridge | publishes | /hexapod/orbslam_odom,
/orbslam/map_points, and /scan, but it does not
publish a competing odom -> base_link transform in the fused launch configuration. The bridge also publishes or launches the static transform from base_link to orbslam_scan_frame, using the measured 11 in, or 0.2794 m, forward camera offset.
This ownership split fixed several practical visualization problems. When both ORB-SLAM and the kinematic stack attempted to own the same odometry transform, the robot skeleton could move in a different frame than the occupancy grid. When ORB-SLAM packets were converted from camera optical axes twice, the camera-forward direction appeared as the wrong robot axis and points that should have appeared in front of the robot appeared above it. When packet timestamps from the bare-metal ORB-SLAM process were used inside the container without synchronized clocks, slam_toolbox and RViz could drop scans due to TF extrapolation. The final bridge disables the second axis conversion, uses local receive stamps by default, and can stamp scans with the latest pose stamp.
V. ORB-SLAM2 CUDA, UDP BRIDGE, AND OCCUPANCY MAPPING
The ORB-SLAM2 CUDA RealSense package was modified so that it is more robust in the deployed Jetson workflow. The RealSense pipeline now retries startup, restarts after repeated frame timeouts, validates aligned color and depth frames before tracking, clones frame memory before handing images to ORB-SLAM2, and skips malformed frames instead of passing empty or mismatched matrices into the tracker. These changes were made to reduce runtime crashes and segfault-like failures caused by transient camera, alignment, or frame-buffer issues.
The deployed ORB-SLAM2 process is run by a systemd service on the Jetson outside the ROS 2 container so that the CUDA-enabled ORB-SLAM2 build and CUDA/OpenCV library paths remain under direct system control. The service runs the RealSense RGB-D executable at 640 by 480 and 30 Hz, sends UDP packets to 127.0.0.1:5005 when the ROS 2 container uses host networking, restarts on failure, and uses SIGINT for clean shutdown. Environment variables enable UDP pose, sparse map chunks, ROS-axis output, and the depth-derived scan stream.
The RGB-D input path was also corrected for metric consistency. Depth is aligned to the color stream every frame, converted from RealSense Z16 units to CV_32FC1 meters, and paired with YAML files using DepthMapFactor:
1.0. This avoids mixing unscaled integer depth units with meter-scale assumptions. The UDP output path can publish pose and map points in ROS axes by default, using +x forward, +y left, and +z up. On the ROS 2 side, the bridge default disables a second axis conversion to avoid doubletransforming the ORB output.
The | ROS | 2 | UDP | bridge | pub-
lishes | /hexapod/orbslam_odom,
/orbslam/map_points, and a lightweight virtual /scan. The virtual scan is extracted from a horizontal depth band, decimated to reduce CPU load, and then consumed by slam_toolbox to produce the 2D occupancy grid intended for Nav2 navigation. The bridge also applies the measured 11 in forward camera offset from base_link. The final launch defaults use a position and scan-range scale of 1.382, scan publish decimation of 3, packet stamps disabled to avoid host/container clock skew, and scan stamps tied to the latest pose stamp to avoid TF extrapolation drops. On the ORB-SLAM2 sender, the service uses 240 scan rays, a 24-pixel vertical band, and a 0.45–3.0 m range window. Sparse map chunks are decimated before transmission and limited to small point packets so that map visualization does not starve pose and scan traffic.
A key lesson is that the sparse ORB map point cloud is not itself the occupancy map. ORB-SLAM2 provides sparse landmarks and camera motion, while slam_toolbox constructs the occupancy grid from the virtual scan. Keeping those products separate made debugging much easier: ORB map points were used to verify axes and visual scale, while the occupancy grid was used to evaluate whether the robot could support Nav2 navigation goals and later costmap-based obstacle avoidance.

VI. FOOT CONTACT SENSING AND FSR LIMITATIONS

The intended leg odometry model included foot-ground contact from FSRs so that stance legs could be selected from hardware contact measurements rather than inferred entirely from linkage phase. In practice, assessing FSR effectiveness was difficult with the available ESP32 ADC inputs. The ADC readings swung widely enough that repeatable, verifiable contact state was not available during the final software integration period. Because a false contact can corrupt the no-slip body-twist solve as badly as a missed contact, the final deployed body-kinematic estimator relies primarily on phase-derived stance confidence from the Klann model. This does not mean FSRs are ineffective for the robot; it means this particular hardware and software path was not yet calibrated enough to trust them as odometry gates. A useful follow-up would add better analog conditioning, stable voltage references, shielded routing away from motor noise, per-sensor calibration under known loads, and software hysteresis with debounced contact state. Once the ADC path is stabilized, FSRs should improve the estimator because they can distinguish true stance from unloaded swing or slip conditions. Until then, the encoder phase is already accurate enough to track tripod gait phase, provided the RS485 polling rate stays fast enough to avoid single-turn wrap ambiguity. The final software therefore treats FSRs as a future contact-quality improvement, not as a required source for odometry. The kinematic estimator already has a phase-derived stance confidence from the Klann trajectory. Hardware contact would improve robustness during slip, uneven loading, or gait transitions, but only after the contact state is repeatable enough that it does not introduce false stance constraints. This was a deliberate safety decision: an untrusted contact signal can make dead-reckoned odometry worse than a purely model-based stance estimate.

VII. EVALUATION RESULTS AND REMAINING LIMITATIONS

The final teleoperation tests showed that the body-kinematic odometry can satisfy the project tolerance for straight-line motion after calibration. The main quantitative calibration trial moved the robot 73 in, or 1.854 m. The uncalibrated kinematic odometry reported approximately 0.851 m in the forward axis with very small lateral drift, which led to the final body_twist_axis_scale value of 2.1786. After applying the final sign, mirror, and scale corrections, the teleoperated straight-line odometry error was within the 6 in tolerance established for the dance-company collaboration. The reported orientation for that run corresponded to only a small yaw error, approximately 0.033 rad, or about 1.9 deg, during the straight traverse.
This result changes the role of the camera in the system architecture. Since the encoder-plus-linkage estimate is sufficient for the demonstrated navigation tolerance, the camera does not have to be the only source of motion continuity. In autonomous forward iterations, the RGB-D stream can be weighted more heavily toward detecting obstacles, people, and free space for Nav2 costmaps, while kinematic odometry maintains short-term body motion. This is especially relevant for the intended public-use context: a rider’s natural posture can leave legs hanging beside the robot, and those legs can partially block the forward D415 view even though the drivetrain and body controller still need a stable odometry source.
ORB-SLAM scale was also tuned empirically. An earlier 52 in test led to an ORB/scan scale of approximately 1.214. The later 73 in test, in the final launch context, implied a total ORB/scan scale of 1.382. The bridge applies this same scale to pose, sparse map points, and laser scan ranges so that visual odometry and occupancy geometry remain mutually consistent. This is a practical calibration, not proof that all depth and SLAM scale errors are resolved. Additional tape-measured tests should be performed with the final camera exposure, resolution, and depth-filter settings.
This result should be interpreted with care. It demonstrates that the encoder-plus-linkage model is useful and that the final software architecture is directionally correct. It does not prove that the model is globally calibrated for all motions. Curvilinear motion, backward motion, payloaddependent body oscillation, foot slip, and nonideal stance timing can all change the effective body displacement per crank phase. Therefore, the final system should retain both SLAM and kinematic odometry rather than replacing one with the other. The most practical long-term estimator is a fused system in which ORB-SLAM constrains global drift when visual tracking is good, while kinematic odometry supplies continuity through short visual failures, dynamicscene corruption, or temporary loss of mapped features. The remaining limitations are primarily calibration and robustness issues. The kinematic model still needs more tape-measured trials to separately tune the scale for forward, reverse, and yaw motion. The RS485 polling period must remain related to the commanded RPM limit because higher motor speed increases wrapping ambiguity. The FSR hardware path requires analog and software filtering before it can be used as a reliable contact source. Finally, ORB-SLAM2 CUDA is more robust after RealSense and UDP hardening changes, but remains a backported package on constrained hardware; production use should still include process supervision, logging, and a graceful fallback to kinematic odometry.
It is possible that AXIS Dance Company selects this hexapod design for future performances because it was the only S26 hexapod design that succeeded in either navigation or locomotion. That prospective use leaves substantial engineering work: verifying the system in real stages, measuring reliability over longer demonstrations, validating performer-interaction behavior, and tuning locomotion for speed, smoothness, and rider comfort. Mechanical follow-up work could include changing leg orientations, revisiting gait phase offsets, and replacing the six-bar Klann linkage with eight-bar or higher-order walking links whose foot paths can provide flatter stance trajectories and lower vertical body excitation. In terms of hardware selection, moving to reliable higher baud communication like CANbus or multi-turn encoder servos in such circumstances where lead times and instant part availability is less of a concern would also add substantial reliability margins for leg estimation and control, freeing up computational resources on the onboard computer for body optimization and camera-based performer avoidance.

VIII. CONCLUSION

The final code achieved a central project objective: deployable embedded odometry and mapping path for the human-carrying hexapod, enabling it to have the capacity of accurately meeting distance and velocity targets as specified by the project design requirements, either by velocity teleoperation or waypoint navigation by off-stage operators. The ESP32 firmware now minimizes RS485 bus pressure, prioritizes all-zero stop commands, and exports raw single-turn encoder counts rather than fragile embedded phase estimates. The ROS 2 host stack unwraps these encoder counts into continuous output crank phase, computes Klann body-kinematic odometry from stance-foot constraints, and fuse this estimate with ORB-SLAM2-derived odometry in a planar TF tree suitable for Nav2 occupancy mapping. The ORB-SLAM2 CUDA package and ROS 2 UDP bridge were hardened for RealSense frame reliability, metric depth handling, ROS-axis consistency, scan generation and Jetsonclass CPU limits. The resulting system met the 6 in straight-line teleoperation tolerance after calibration, which allows future camera processing to focus more on dynamic obstacle and people avoidance while still leaving clear follow-up work in kinematic scale tuning, FSR contact reliability, broader fused-odometry validation, and stage-readiness testing. Project resources are available through the team website [12], code repository [13], and Desmos linkage model [14].

REFERENCES

[1] Mechatronic Design Spring 2026, “Kinematic/Kinesthetic Dance Robot Specifications,” Version 4.0, course handout.
[2] C. Cadena, L. Carlone, H. Carrillo, Y. Latif, D. Scaramuzza, J. Neira,
I. Reid, and J. J. Leonard, “Past, Present, and Future of Simultaneous Localization and Mapping: Towards the Robust-Perception Age,” IEEE Transactions on Robotics, vol. 32, no. 6, pp. 1309–1332, 2016.
[3] K. Ebadi et al., “Present and Future of SLAM in Extreme Underground Environments,” arXiv:2208.01787, 2022.
[4] R. Mur-Artal and J. D. Tardós, “ORB-SLAM2: An Open-Source SLAM System for Monocular, Stereo, and RGB-D Cameras,” IEEE Transactions on Robotics, vol. 33, no. 5, pp. 1255–1262, 2017.
[5] C. Campos, R. Elvira, J. J. Gómez Rodríguez, J. M. M. Montiel, and
J. D. Tardós, “ORB-SLAM3: An Accurate Open-Source Library for Visual, Visual-Inertial, and Multi-Map SLAM,” IEEE Transactions on Robotics, vol. 37, no. 6, pp. 1874–1890, 2021.

[6] M. Labbé and F. Michaud, “RTAB-Map as an Open-Source Lidar and Visual SLAM Library for Large-Scale and Long-Term Online Operation,” Journal of Field Robotics, vol. 36, no. 2, pp. 416–446, 2019.
[7] B. Bescos, J. M. Facíl, J. Civera, and J. Neira, “DynaSLAM: Tracking, Mapping, and Inpainting in Dynamic Scenes,” IEEE Robotics and Automation Letters, vol. 3, no. 4, pp. 4076–4083, 2018.
[8] C. Yu, Z. Liu, X. Liu, F. Xie, Y. Yang, Q. Wei, and Q. Fei, “DS-SLAM: A Semantic Visual SLAM towards Dynamic Environments,” in Proc. IEEE/RSJ International Conference on Intelligent Robots and Systems (IROS), 2018, pp. 1168–1174.
[9] W. Dai, Y. Zhang, P. Li, Z. Fang, and S. Scherer, “RGB-D SLAM in Dynamic Environments Using Point Correlations,” arXiv:1811.03217, 2018.
[10] UZ-SLAMLab, “ORB-SLAM3,” GitHub repository, accessed Apr. 7, 2026.
[11] B. Bescos, “DynaSLAM,” GitHub repository, accessed Apr. 7, 2026.
[12] Mechatronic Design Spring 2026 Team 2, “Project Website,”
https://mechatronic-design-s2026-team-2.github.io/Website/, (https://mechatronic-design-s2026-team-2.github.io/Website/) accessed Apr. 30, 2026.
[13] Mechatronic | Design | Spring | 2026 | Team | 2, | “De-
sign | Repository,” | https://github.com/
Mechatronic-Design-S2026-Team-2/Design, (https://github.com/Mechatronic-Design-S2026-Team-2/Design) | accessed
Apr. 30, 2026.
[14] Team 2, “Hexapod Klann-Linkage Desmos 3D Model,” https://
www.desmos.com/3d/18nie5ecgp, accessed Apr. 30, 2026.

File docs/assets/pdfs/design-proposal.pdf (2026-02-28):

# Carnegie Mellon University

### College of Engineering – Pittsburgh, PA

Mechatronics Design – Spring 2026 – Dance Robot

# Design Proposal

### Team 2

Team: Daniel Gonzalez Lazaro Yechen Zheng
Hongfei Liu
Hongru Liu

Instructors: Matthew Travers Kaushik Chavali
Juee Chandrachud
Parth Ghube
Alis Bao

Table of Contents

1. Project description |
2. Design requirements |
2.1. Explicit requirements from project specifications |
2.1.1. Form and mobility |
2.1.2. Power and cost |
2.1.3. Construction, aesthetics, and safety |
2.1.4. Sound-level requirements |
2.1.5. Special restrictions |
2.1.6. Setup and operation |
2.1.7. Final demonstration tasks and scoring constraints |
2.2. Implied requirements |
2.3. Requirements stemming from autonomy |
3. Functional architecture |
4. Design trade studies |
4.1. Locomotion and actuation concept trade study |
4.2. Motor selection trade study |
4.3. Compute and sensing trade study |
5. Cyberphysical architecture |
6. System description/depiction |
6.1. Overall system overview |
6.2. Klann linkage locomotion subsystem |
6.3. Side leg subsystem |
6.4. Sensing and compute subsystem |
7. Project management |
7.1. Schedule |
7.2. Team member responsibilities |
7.3. Budget |
7.4. Risk management |
8. References |

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
p. 1
1. Project description

This project develops a compact, legged, human-carrying assistive mobility robot for Kinematic/Kinesthetic, a live performance by the AXIS Dance Company. The goal is to transport a wheelchair user without wheels as the primary locomotor, using articulated legs to enable expressive, choreographed motion and zero-radius turning.

The project frames assistive technology as an artistic medium rather than a device meant to “fix” disability. The design is intended to be compact, safe, and stage-ready, and the current concept includes autonomous features. These statements and requirements are derived from the project specifications as put forth by our partnership with AXIS.

2. Design requirements

2.1 Explicit requirements from project specifications [1]

2.1.1 Form and mobility

A. Locomotion must be controlled/initiated through use of legs. Load bearing may be supported by auxiliary wheels, treads, or an alternative mechanism.
B. Footprint shall not exceed 5 ft × 5 ft.
C. User ride height shall be 2 ft to 3 ft off the ground.
D. Device mass shall not exceed 150 lb.
E. Device shall carry a person up to 170 lb and account for additional dynamic forces during use.
F. User may sit cross-legged or in a standard seated chair position.
G. Device must travel in at least two directions: forward and backward.
H. Device must have a zero-degree turning radius, with clockwise and counter-clockwise rotation.
I. Device must reliably navigate to a designated point in space within a tolerance of 6 in within 1 minute.
J. Device must be shippable in a 3 ft × 3 ft × 3 ft case, disassembled into no more than 7 parts.
K. Ability to fit through a 36 in door when folded (no disassembly required) is preferred.

2.1.2 Power and cost

A. Battery life shall be at least 30 minutes.
B. Guideline reimbursable limit for total purchased parts/materials cost is approximately $900.

2.1.3 Construction, aesthetics, and safety

A. Device must be robustly constructed (nuts/bolts, machine screws, cable ties, proper soldering, etc.). No prototype kits or toys may be used. Appearance counts.

p. 2
B. Device must not damage anything with which it interacts. No rough edges, burrs, exposed screw tips, etc.
C. Ride must be sufficiently smooth for the user to ride safely without being strapped to the device.
D. Device must include emergency stop controls.
E. Surrounding environment safety must be considered (robot is used around people during performance).

2.1.4 Sound-level requirements

A. Sound level shall remain under 70 dB during normal operation (traversal, rotation, etc.) measured at 5 ft from robot center using the Decibel X application.
B. Peaks of 85 dB are acceptable only for short periods; total peak duration shall not exceed 1 s for every 60 s of operation.

2.1.5 Special restrictions

A. Teams may not use a laptop in the final machine (allowed for testing/debug).
B. A cell phone or webcam may be used only if it remains part of the machine throughout the course.

2.1.6 Setup and operation

A. Assembly from packed states shall take no more than 15 minutes and shall not require soldering, heavy machinery, etc.
B. Control options allowed include: pre-programmed path, remote control by an operator 20 ft to 50 ft away, or user joystick control.

2.1.7 Final demonstration tasks and scoring constraints

A. The system must complete taped-course tasks while carrying a payload of 150 lb
a. Reach a designated point 10 ft away in 1 minute via a straight path.
a. Reach a designated point 10 ft away in 90 seconds via a curvilinear path.
b. Reach a point 10 ft away in 90 seconds driving backward via a straight path.
c. Reach a point 10 ft away in 2 minutes driving backward via a curvilinear path.
B. The system must withstand the impact of a 25 lb weight dropped from a height of 5 ft.
C. Performance scoring includes task completion time bands, penalties for deviating from the designated path, and penalties for manual intervention.

2.2 Implied requirements

A. "Appearance counts" and the "no rough edges" rule imply a need for professional finishing like sanding, painting, or deburring.
B. Since the user is 2'–3' high and unstrapped, the gait must remain extremely level to prevent tipping.

p. 3
C. A 6" navigation tolerance suggests the need for encoders or sensors rather than simple "timed" motor movements.
D. To stay under 70dB, we must likely avoid noisy metal gears or high-frequency motor whine.
E. The 30-minute battery life and "no benchtop power" rule imply a need for on-board voltage regulation and battery monitoring

2.3 Requirements stemming from autonomy

Camera-driven autonomy is the project’s distinguishing feature: perception is used first to enforce safety around the rider and nearby performers, and then to enable reliable point-to-point navigation across the performance space.

A. Goal requirements
a. Any computer required for perception and autonomy must remain on-board.
b. The robot has at least one autonomous operating mode in addition to manual control options.
c. The perception stack produces a continuously updated hazard field (free/occupied or safe/unsafe space) from on-board sensing at a responsive rate while moving.
d. The robot maintains a buffer around detected obstacles; any violation triggers an automatic stop.
e. Emergency stop controls that immediately inhibit motion commands and place the robot in a safe state.
f. The robot can navigate to a designated waypoint within a 6-inch tolerance within 1 minute using only on-board components.
g. Robot autonomy continues to enable forward/backward travel and zero-radius clockwise/counter-clockwise rotation.
h. The robot detects unlikely sensing inputs and automatically falls back to safe state.
i. The robot publishes telemetry sufficient for safe testing and debugging (pose estimate, commanded velocity, safety state, and power status) while allowing manual override at any time.
j. The power system can sustain autonomous sensing and navigation operation for at least 30 minutes on battery.
B. Stretch goal requirements
a. The robot detects moving obstacles and estimates their short-horizon motion to reduce nuisance stops in the presence of nearby performers.
b. The robot autonomously re-routes around moving obstacles while maintaining a minimum separation buffer.
c. The autonomy stack is resistant to lighting and texture changes typical of performance spaces, maintaining stable perception outputs.
d. The system shall support choreographed multi-waypoint sequences where timing and path shape are repeatable run-to-run using on-board sensing.
e. The system provides a “safety bubble” visualization or status indicator that communicates when the robot is in safe-to-approach vs stop/avoid states to nearby assistants/operators.

p. 4
3. Functional architecture

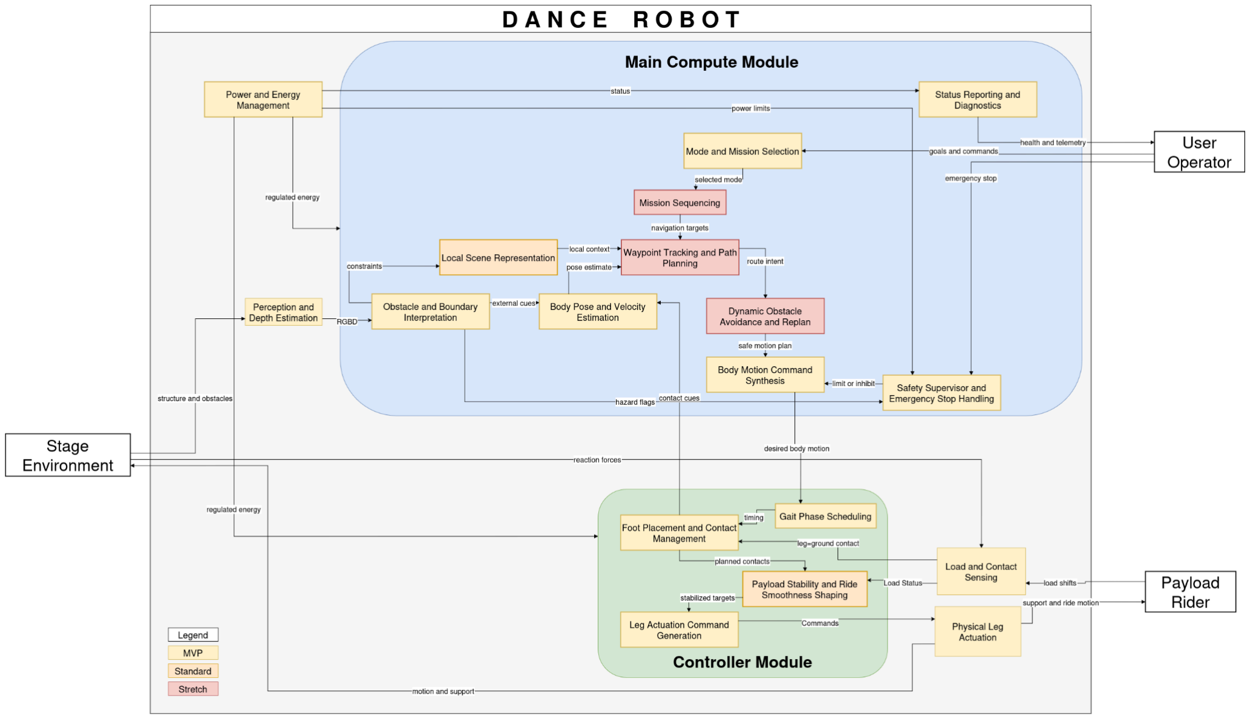
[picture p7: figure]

Figure 1. Functional architecture diagram.

The functional architecture decomposes the dance robot into a small set of purpose-specific functions that together enable safe, repeatable legged transport of a rider through an indoor space. At the top level, Mode and Mission Selection supports the allowed operating modes (pre-programmed motion, remote operator control, and user-driven joystick control), and provides a single place to arbitrate goals and permissions before any motion is commanded. A lightweight Status Reporting and Diagnostics function closes the loop for development and testing by exposing internal state, safety flags, and motion intent to the operator interface; however, the long-term intent is that the system remains fully embedded and portable, avoiding dependence on an external laptop during normal operation.

In the mobility pipeline, Body Pose and Velocity Estimation produces the robot-centric state needed to command controlled motion, while Obstacle and Boundary Interpretation provides environmental constraints (e.g., boundaries and hazards) used to limit motion near people and stage objects. These signals feed Body Motion Command Synthesis and the locomotion stack (Gait Phase Scheduling, Foot Placement and Contact Management, and Leg Actuation Command Generation), which together convert high-level motion intent into stable stance/swing timing and leg-level commands. This chain is directly responsible for meeting the fundamental mobility requirements, including forward/backward travel and zero-radius turning in both directions.

p. 5

The autonomy capability is introduced as a standard feature through Local Scene Representation and Waypoint Tracking and Path Planning, which support navigation to a designated point within the required tolerance and time budget while carrying a rider. The architecture treats Dynamic Obstacle Avoidance and Replan as a stretch feature: it improves robustness in the presence of moving people by enabling reactive re-planning, but it is not required for fundamental operation because a remote operator can instead command velocities and manage avoidance during early demonstrations. Safety Supervisor and Emergency Stop Handling is a cross-cutting function that can inhibit or limit motion when hazards are detected, ensuring safe operation for the rider and surrounding environment and providing explicit emergency stop capability. Finally, Power and Energy Management regulates energy distribution and enforces power limits in support of sustained operation, including the 30-minute battery-life requirement.

4. Design trade studies

This section evaluates the critical architectural decisions for the Team 2 Dance Robot, focusing on how selected mechanical and electronic components fulfill the unique requirements of the AXIS Dance Company performance—specifically the need for a 170 lb payload capacity, a $900 budget, and "species atypical" movement.

4.1 Locomotion and actuation concept trade study

The primary challenge is selecting a leg mechanism that balances mechanical simplicity with the stability required for an unstrapped rider. We compared the Klann Linkage against the Jansen Linkage (popularized by the Strandbeest) and high-DOF Articulated Robotic legs.

Table 1. Locomotion and actuation concept trade study.

Feature | Klann Linkage | Jansen Linkage | Articulated (3-DOF)
Complexity | Moderate (6 links per leg) | High (8-12 links per leg) | High (Software-intensive)
Actuators | 1 motor can drive 3 legs | 1 motor can drive 3 legs | 3 motors per leg (18 total)
Control Ease | Simple: Gait is mechanically encoded | Simple: Gait is mechanically encoded | Difficult: Requires Inverse Kinematics
Payload | Excellent: Robust force transmission | Moderate: Many joints increase flex | Variable: Limited by motor torque
Step Height | High; good for obstacle clearance | Relatively low; "strandbeest" style | Fully adjustable via software
Aesthetics | biological "walk" | biological "walk" | Realistic, insectoid movement

p. 6

We selected the Klann linkage over the Jansen linkage or articulated legs to meet the high-stakes demands of an AXIS Dance Company performance, prioritizing mechanical reliability, payload dynamics, and safety. By mechanically encoding the walking gait, the Klann linkage eliminates the "software trip" risks inherent in complex Inverse Kinematics, ensuring the rider’s safety is hard-wired into the physics of the machine rather than dependent on a digital control loop. This 6-bar mechanism excels in vertical force transmission, efficiently distributing the 320 lb system load across structural links to protect motor gear teeth from excessive stress. Furthermore, the Klann design offers superior step clearance compared to the Jansen linkage, providing the reliability needed to navigate stage obstacles and taped courses without snagging.

4.2 Motor Selection Trade Study

The primary drive motors must provide enough torque to rotate the Klann crankshafts under a total system load of approximately 320 lbs (170 lb rider + 150 lb robot) while remaining under the $2500 budget and 70 dB noise limit. We compared three distinct motor architectures:

Table 2. Drive Motor Selection for Klann Crankshafts

Selection Criteria | High-Torque DC Gear Motor | Smart Servo (e.g., Dynamixel) | NEMA 23 Stepper + Gearbox
Torque Output | Excellent: High reduction ratios provide massive lifting force. | Moderate: High torque models are extremely expensive. | High: Great holding torque, but loses torque at speed.
Cost (per unit) | Low ($40–$80): Leaves more budget for structural aluminum. | High ($150–$300): Would exceed the $900 project limit. | Medium ($80–$120): Requires expensive high-current drivers.
Control Logic | Simple: PWM for speed and H-bridge for direction. | Complex: Requires specific TTL/RS485 bus communication. | Moderate: Requires pulse/direction step counting.
Acoustics | Quiet: Low-RPM operation helps meet <70 dB requirement. | Variable: High-frequency PWM whine can be noisy. | Noisy: Distinctive "stepping" vibration and resonance.
Feedback | External: Requires separate encoders for 6" precision. | Internal: Built-in high-resolution encoders. | Open-Loop: Risk of losing steps under heavy payload.

We selected High-Torque DC Gear Motors for their superior performance-to-cost ratio, specifically tailored to the Klann linkage’s mechanical demands. High reduction ratios provide the necessary "force multiplication" to prevent stalling during the high-load stance phase, while their cost-effectiveness allows budget reallocation toward the frame durability required for the 25 lb impact test. Furthermore, these motors support the 30-minute battery life requirement through better efficiency than stepper motors and meet the 6-inch navigation tolerance when paired with encoders. Finally, by operating at low RPMs to maintain a 1–4 mph walking speed, the motors stay well below the 70 dB threshold, ensuring acoustic compliance for the AXIS Dance Company performance.

p. 7

4.3 Compute and Sensing Trade Study

The selection of the primary compute node and exteroceptive sensors is governed by the need for real-time obstacle detection and precise navigation. Given the requirement for autonomous point-to-point travel and a 30-minute battery life, the system must balance high computational throughput for image processing against power efficiency.

Table 3. Comparison of low-cost computers appropriate for embedded projects

Feature | Raspberry Pi 4 | Raspberry Pi 5 | Nvidia Jetson Nano
Processor (CPU) | Broadcom BCM2711 (Quad-core) | Broadcom BCM2712 (Quad-core) | Quad-core ARM A57
GPU/AI Acceleration | No dedicated hardware | No dedicated hardware | 128-core Maxwell (CUDA)
RAM | 8GB LPDDR4 | 8GB LPDDR4X | 4GB LPDDR4
ROS2 Compatibility | Excellent (Ubuntu 22.04) | Excellent | Fair (Supports older versions)
Power Draw | 5-8W | 12-15W | 5-10W

We have selected the Nvidia Jetson Nano. While the Raspberry Pi 4 and 5 offer competitive general-purpose computing and lower price points, the Jetson Nano’s CUDA cores are essential for processing depth-map point clouds. To ensure rider safety in a dynamic dance environment, we require low-latency object detection. The Jetson Nano’s dedicated GPU allows us to run computer vision algorithms more efficiently while maintaining a sustainable power draw for the 30-minute battery life requirement.

p. 8
5. Cyberphysical architecture

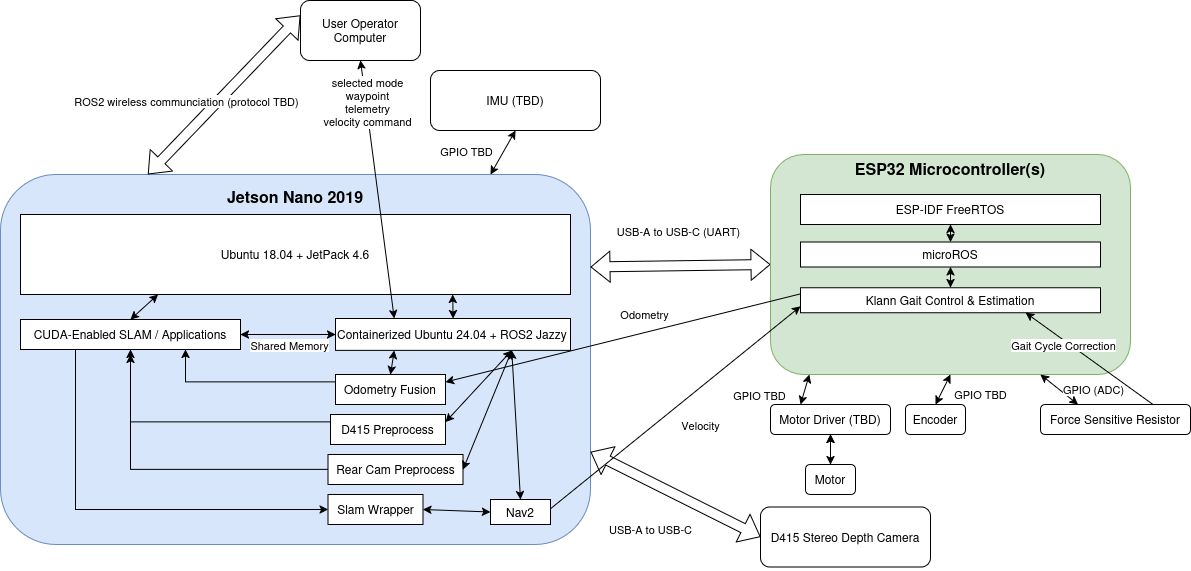
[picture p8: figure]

Figure 2. Cyberphysical architecture diagram.

The cyberphysical architecture partitions the robot into a high-level autonomy computer and a set of low-level real-time controllers. An embedded compute node (Jetson Nano) runs the perception and navigation stack in ROS2, while one or more ESP32 microcontrollers execute deterministic gait control, actuator interfacing, and local estimation under an RTOS. This split keeps the “heavy” workloads (camera processing, mapping/localization, and planning) on the Jetson, while timing-critical motor/encoder/foot-contact I/O stays on the ESP32 side.

In operation, the user/operator computer exchanges ROS2 messages wirelessly with the Jetson to set the active mode and provide mission inputs (e.g., waypoint commands or direct velocity commands consistent with allowable control modes). Onboard sensing enters through the depth camera (RealSense D415), optional rear camera, and IMU. The Jetson performs sensor preprocessing (camera pipelines, IMU ingestion), fuses proprioceptive and perception-derived estimates into a body pose/odometry state, and feeds that state to the navigation layer (SLAM wrapper and Nav2). The navigation layer produces body-level motion intent (velocity commands) that are sent over a UART link (USB-A to USB-C) to the ESP32 microcontroller(s). The ESP32 executes the gait controller and closes the low-level loops using encoder feedback and foot-contact proxies (e.g., force-sensitive resistor), producing motor-driver commands and applying gait-cycle correction. Low-level odometry and gait state are returned to the Jetson for fusion and for telemetry back to the operator station. Safety is treated as a first-class cross-cutting path: emergency stop controls are required, and hazard/power-limit conditions are expected to be able to inhibit or clamp commanded motion at the compute and/or microcontroller layers.

p. 9
6. System description/depiction

6.1 Overall system overview

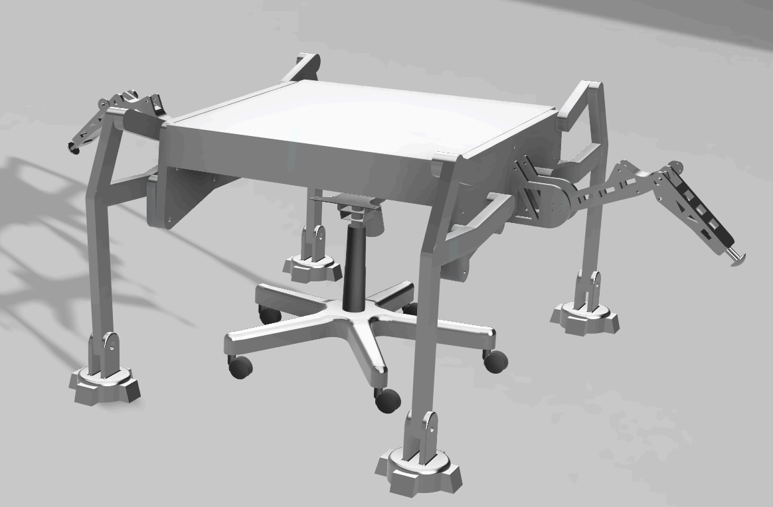
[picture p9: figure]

Figure 3. System depiction – overview.

The system consists of four primary subsystems: the main base structure, the wheel support assembly, one set of side legs and two sets of Klann-linkage-style legs. The main base structure provides the primary load-bearing platform and supports the seated performer. It serves as the structural backbone of the system and integrates all major mechanical components.

Beneath the main base, an electronics compartment is integrated between the main base and the wheel support assembly. This enclosed space houses the power distribution system, motor drivers, microcontrollers, wiring harnesses, and sensor modules. Locating the electronics centrally lowers the center of gravity, improves mass distribution, and protects sensitive components from external impact and debris.

The wheel support assembly is designed to carry the majority of the system weight. It provides static stability and reduces the load transmitted to the leg mechanisms during operation, thereby improving overall efficiency and durability.

p. 10

The Four Klann-linkage leg assemblies are responsible for generating forward and backward locomotion. In addition, a pair of side-mounted legs driven by linear actuators are dedicated to lateral motion.

6.2 Klann linkage locomotion subsystem

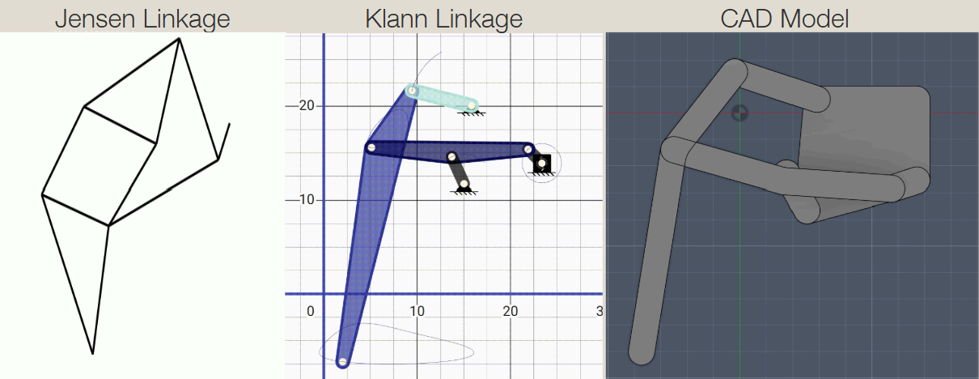
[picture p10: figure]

Figure 4. Klann design process

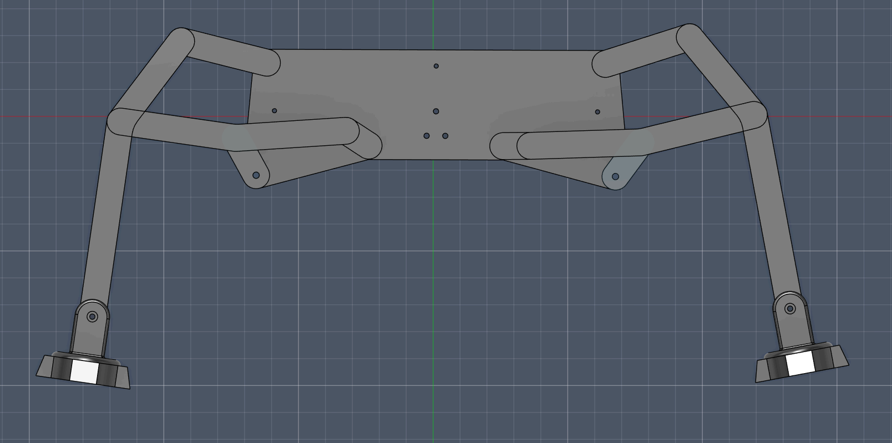
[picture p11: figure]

Figure 5. System depiction – Klann linkage.

To minimize the total number of actuators while maintaining effective walking performance, the team evaluated multiple linkage mechanisms capable of converting rotary motion into a walking gait. After comparative analysis, the Klann linkage was selected as the primary leg mechanism. Compared to the Jansen linkage, the Klann mechanism consists of fewer

p. 11

links and joints, resulting in a mechanically simpler architecture with reduced assembly complexity, fewer tolerance stack-up concerns, and lower maintenance requirements.

In the current design, rotary DC gear motors drive the Klann crank shafts. Each crank shaft is supported by appropriate shaft support hardware, including bearings, shoulder bolts, linkage plates, pivot joints, and foot pads, as outlined in the mechanical budget. One motor is used per side of the system, driving the corresponding set of leg linkages.

These leg assemblies convert continuous rotary input into a cyclic walking trajectory, producing stable ground contact and forward propulsion. The synchronized linkage motion ensures consistent footfall patterns and load distribution during locomotion.

Turning is implemented using a differential-drive strategy similar to that of a tracked vehicle. By independently controlling the rotational speeds of the left and right motor-driven leg sets, the system can achieve zero-radius (0 radian) turning about its vertical axis.

6.3 Side leg subsystem

The side legs provide active stabilization, pose control, and lateral (side-to-side) body translation during locomotion and expressive motion. Specifically, they (1) increase the support polygon to reduce tip risk under payload, (2) help maintain rider height in the target range (2–3 ft), (3) enable controlled body roll/pitch for choreographed movements, and (4) provide controlled lateral shifting to reposition the body relative to the stance legs—supporting balance recovery and expressive “side glide” motions while staying within the 5’×5’ footprint requirement.

Each side leg is an articulated link assembly with an end foot pad, driven by a compact linear actuator (motor-internal) through a pinned joint/clevis interface. The CAD shows a multi-link arm with cutouts for weight reduction and mounting interfaces to the main frame.

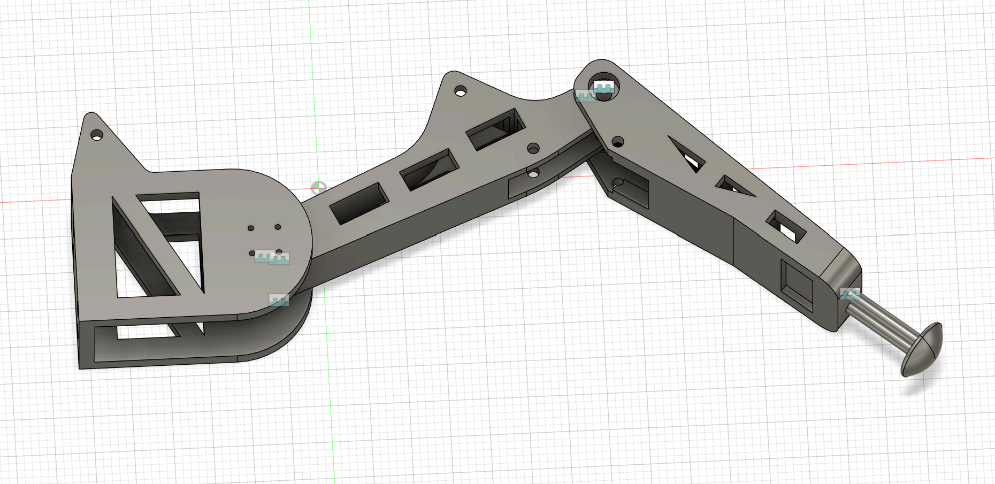
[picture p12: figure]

Figure 6. System depiction – side legs.

We baseline linear actuators (motor inside) for side-leg actuation due to relatively low integration complexity, precise position control, and reduced safety concerns compared with fluid power. Our provisional mechanical budget already includes two linear actuators with

p. 12

100–200 mm stroke and 300–1000 N force range, along with clevis/rod ends and actuator mounting brackets.

However, due to expected cost, integration complexity, and stage-safety considerations, the current direction is shifting toward a motor-driven mechanism to achieve the required stabilization and lateral-shift motions with simpler integration into the overall electromechanical system.

6.4 Sensing and compute subsystem

The sensing and compute subsystem supplies basic environment awareness and motion state estimates needed for safe operation and (when enabled) waypoint navigation. It uses a forward stereo depth camera as the primary exteroceptive sensor, with an auxiliary rear-facing camera path for backing/turning awareness and an IMU for short-term motion stabilization and disturbance detection. Onboard compute handles sensor preprocessing and publishes perception/state outputs to the autonomy and safety layers, supporting teleoperation during early testing and autonomous navigation in later phases.

7. Project management

7.1 Schedule

Table 4. Schedule

| W5 | W6 | W7 | W8 | W9 | W10 | W11 | W12 | W13 | W14 | W15

CAD Design

Simulation

Locomotion Control Implementation

Assembly

Circuit Assembly

Localization Implementation

Full Assembly Testing

Computer system setup

Computer system testing

Table 4 shows a high-level, abbreviated form of our plan for the remainder of the semester with regards to every major component of our robot prototype. Please refer to our github organization and project (found in team website) for per-task scheduling.

p. 13

7.2 Team member responsibilities

Table 5. Member responsibilities.

Team Member | Primary Responsibilities | Secondary Responsibilities
Daniel Gonzalez Lazaro | ● Systems Integration ● Microcontroller programming ● ROS2 programming ● Github management ● Website updating ● SLAM implementation ● Power circuit ● Sensor and computer circuit | ● Locomotion control implementation ● Simulation setup and troubleshooting
Yechen Zheng | ● Mechanism Design ● Parts manufacturing ● Robot Fabrication and Assembly | ● Control Optimization ● Gait simulation
Hongfei Liu | ● Assembly ● Locomotion control optimization ● Parts manufacturing ● Robot Fabrication and Assembly
Hongru Liu | ● Assembly ● Parts tracking and ordering ● Parts manufacturing ● Robot Fabrication and Assembly

7.3 Budget

Table 6. Allocation of $2500 Motor Stipend

Item | Description / Notes | Qty | Unit Cost (USD)
DC gear motors (Klann drive) | Rotary motors | 2–4 | 300-500

Table 7. Estimated budget.

Motor mounting brackets | Motor-to-frame mounts | 2–4 | 15–50
Shaft couplers | Motor-to-crank shaft couplers | 2–4 | 10–30
Crank shafts | Steel or aluminum shafts | 2–4 | 15–50

p. 14
Pillow block / radial bearings | Support crank shafts | 4–8 | 10–40
Shaft collars | Axial shaft retention | 6–12 | 5–15
Klann linkage plates | Aluminum / G10 link sets | 4 sets | 25–120
Shoulder bolts / joint pins | Klann pivot joints (M5–M8) | 4 sets | 15–60
Bearings / bushings | Flanged bearings or bronze bushings | 4 sets | 20–80
Spacers & washers | Aluminum / nylon spacers | 4 sets | 5–20
Klann foot pads | Rubber / TPU feet | 4 | 5–25
Klann leg mounting brackets | Leg-to-frame interface | 4 | 10–50
Linear actuators (motor inside) | 100–200 mm stroke, 300–1000 N | 2 | 40–250
Clevis / rod ends | Actuator end joints | 4 | 10–40
Actuator mounting brackets | Frame and leg mounts | 2 sets | 20–60
Actuator leg structures | Links / tubes for actuator legs | 2 sets | 20–60
Actuator leg bearings | Pivot bearings / bushings | 2 sets | 10–30
Actuator leg foot pads | Rubber / TPU feet | 2 | 5–25
Main frame extrusions / plates | 6061 aluminum | 1 set | 150–600
Side plates / hubs | Thick leg-mount plates | 2–4 | 40–200
Cross bracing / gussets | Structural stiffening | 1 set | 30–150
Standoffs / spacers | Frame spacing | 1 set | 20–100
Fastener assortment | M3–M8 bolts, nuts, washers | 1 lot | 50–200
Thread inserts | Heat-set or press-fit | 1 lot | 10–60
Adhesives & consumables | Loctite, epoxy | 1 lot | 10–40
Battery | Powering systems | 1 | 150
Office chair | | 1 | 80
Fabrication allowance | Extra material / mistakes | | 10–25%

Thus the estimated total, excluding motors is in the range of $670–$1300

p. 15

7.4 Risk management

We have identified the following potential issues in constructing our prototype:

Side leg size/geometry not finalized: If the side-leg length or placement is wrong, it can cause mechanical interference, reduce stability under payload, or violate footprint/foldability constraints. Mitigation: define a fixed kinematic/packaging envelope early, run quick CAD interference checks across worst-case poses (extended, retracted, turning, folded), and freeze geometry before releasing parts.

Actuation selection uncertainty (hydraulic / pneumatic / motor / linear actuator): The side-leg actuator choice drives force capacity, controllability, noise, safety, and integration; a poor choice could yield inadequate performance or unsafe behavior. Hydraulics are likely too costly/complex and pneumatics may not hold position reliably, so the current direction is a motor-driven solution. Mitigation: set minimum force/stroke/speed/noise targets, bench-test a short list of candidates, and keep mounts modular so we can swap actuators without redesigning the chassis.

Materials and joint hardware not selected: Poor material/joint choices can lead to buckling, backlash, and wear, reducing stability and safety. Mitigation: standardize pivots using shoulder bolts/joint pins with bearings/bushings, follow the planned structural material approach, and do quick worst-load strength sanity checks before fabrication.

Late design decisions delay ordering and integration: Delays in freezing side-leg geometry/actuation can push back CAD release, procurement, assembly, and system testing. Mitigation: enforce a design-freeze milestone, order long-lead/common components early, and integrate in stages so base locomotion and controls testing can proceed in parallel.

Budget creep from actuator/frame changes and rework: Upgrades, custom machining, and iteration can exceed the mechanical budget. Mitigation: maintain a live budget with contingency, favor off-the-shelf parts and simple fabrication, and prototype high-uncertainty subsystems cheaply before committing to final hardware.
8. References
[1] Kinematic/Kinesthetic Dance Robot Specifications, Mechatronic Design Spring 2026, Version 4.0.
[2] NVIDIA Corporation, "Jetson Nano Developer Kit Data Sheet," v1.1, 2019. https://developer.nvidia.com/embedded/jetson-nano
[2] Raspberry Pi Foundation, "Raspberry Pi 4 Model B Product Brief," 2019. https://www.raspberrypi.com/products/raspberry-pi-4-model-b/
[3] Microsoft Corporation, "Xbox Adaptive Controller Technical Specifications," 2018. https://www.xbox.com/en-US/accessories/controllers/xbox-adaptive-controller
[4] Logitech G, "F310 Gamepad Technical Specifications," 2023. https://www.logitechg.com/en-us/products/gamepads/f310-gamepad.html

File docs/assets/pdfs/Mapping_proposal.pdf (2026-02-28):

A Staged Proposal for Resource-Constrained Odometry, Localization,

## and Mapping on a Human-Carrying Hexapod

Daniel Gonzalez Lazaro

Abstract— I propose a staged odometry, localization, and mapping project for a human-carrying dance robot built around a Jetson Nano, a RealSense D415, and a micro-ROS ESP32. The robot is being constructed as a capstone project for 18-578 Mechatronic Design, so early experiments will rely on RGB-D and IMU sensing before leg-derived odometry is available. The goal is to identify a deployable embedded pipeline that can support designated-point navigation, forward and backward motion, and curvilinear indoor traversal on a low power platform. The main contribution is a resource-aware evaluation of perception pipelines developed before full robot completion and then transferred to the hexapod once encoder and touch-sensor odometry become available pending leg fabrication.

I. INTRODUCTION AND MOTIVATION

The target platform is an assistive mobility device for AXIS Dance Company that must transport a rider without wheels as the primary locomotor, fit within a 5 ft by 5 ft footprint, carry up to a 170 lb rider while keeping the total system mass below 150 lb, and navigate to a designated point in a performance stage within 6 in in 1 min [1]. The final demonstrations also require straight and curvilinear forward and backward traversals over 10 ft in a test area of 10 ft by 10 ft, with penalties for path deviation and manual intervention [1]. These requirements make odometry, localization, and mapping central rather than peripheral. Although teleoperation is allowed for a minimum viable product, dead reckoning from the perspective of an operator from behind or otherwise outside of the stage is unreliable to meet accuracy specifications, and riders of the hexapod would be primarily concerned with their dance performance to control the platform instead. Therefore, if the robot cannot estimate its motion, localize on a room-scale map, and plan repeatable trajectories, it will not meet the navigation portions of the course specification.
This project focuses on the perception stack needed for those tasks on a compute-limited onboard platform. The course specification forbids the use of a laptop on the final machine and requires at least 30 min of battery-powered operation [1]. A 1000 USD budget is provided for all new part acquisitions, mostly allocated towards the physical robot assembly. Therefore, I am effectively constrained to a Jetson Nano (2019) platform from existing course materials. That embedded constraint is scientifically interesting because the performance of SLAM is strongly affected by robot type, sensing, environment, and resource limits [2], [3]. Therefore,

This proposal overlaps with the Mechatronic Design Spring 2026 hexapod project. The overall robot is a team effort for that course, with my colleagues Yechen Zheng, Hongfei Liu, and Hongru Liu, but the odometry, localization, mapping, and SLAM stack proposed here are my individual responsibility.

my aim is not to invent a new SLAM algorithm but to determine which odometry and mapping pipeline is feasible and useful for this specific robot.

II. PROPOSED WORK AND NOVELTY

The robot design is intended to include fused odometry from motor encoders, foot-contact sensors, IMU measurements, and exteroceptive sensing. However, the legs must be built before the encoder and touch-sensor feedback is available. Therefore, I will use a staged plan.
In the first phase, I will configure the entire Jetson software stack, including ROS 2, containerized autonomy, D415, and IMU measurements delivered from an ESP32 through micro-ROS. In the following two weeks, the odometry and mapping experiments will primarily be based on D415-based RGB-D sensing plus IMU data. In the second phase, once the legs are available, I will add proprioceptive odometry from motor encoders and foot-contact events and evaluate whether fused estimation improves localization stability during real locomotion.
The novelty is the staged, resource-aware evaluation itself. I will compare methods that are realistic on the final embedded platform and quantify how well an early perception stack transfers to the completed robot. Given that this is a mobility device for stage performance, it faces additional challenges of obstacles at variable heights, highly dynamic lighting conditions, and perhaps even dynamic obstacles. Therefore, this is a useful contribution even if individual algorithms are standard, as the literature emphasizes that robust SLAM remains deployment-dependent and that evaluation under challenging conditions is still a major need [2], [3].

III. METHODS

I will compare three progressively richer configurations. Baseline odometry: RGB-D odometry from the D415, optionally aided by IMU measurements from the ESP32, without loop closure. This provides a lower-compute baseline and an estimate of drift under the motion patterns expected in the course tests.
Mapping and loop closure: a SLAM pipeline that builds a room-scale map and performs global correction through relocalization or loop closure. The exact package may be adjusted to match Jetson performance, but it will use concepts from the course: state estimation, scan or image registration, probabilistic localization, and map-based correction. It is likely that some adaptation of packages will be necessary, especially in leveraging CUDA capabilities, due to the platform’s EOL status.

Late-stage fused odometry: once the robot legs are operational, I will augment the exteroceptive stack with proprioceptive signals from motor encoders and foot-contact sensing. This stage tests whether fused odometry reduces drift and improves robustness during forward, backward, and turning maneuvers on the actual hexapod.
The output map representation will be chosen to support navigation rather than only visualization. In practice, that means producing a localization and mapping product that can support waypoint placement, designated-point driving, and curvilinear motion within the course testbed.

IV. EVALUATION, METRICS, AND CHALLENGES

Success will be measured both as a SLAM problem and as a robot-task problem. For estimation quality, I will measure trajectory drift on repeated loops, relocalization repeatability, map consistency, and runtime on the Jetson Nano. For robotrelevant performance, I will evaluate whether the perception stack enables the machine to reach a designated stage target within the course tolerance of 6 in, reduce path deviations during 10 ft straight and curvilinear tasks, and reduce or eliminate manual intervention during forward and backward operation [1]. Because the final robot must rotate in place and move in multiple directions [1], I will also evaluate turning stability and backward-motion localization rather than only forward trajectories.
I will explicitly profile embedded feasibility. The final machine must run onboard without a laptop and must maintain a 30 min battery budget [1]; therefore, a method that is slightly more accurate but too slow or power-hungry will not be considered successful.
The main technical challenges are foreseeable. Early experiments must be carried out before the full robot exists, so I need a perception stack that can be developed from D415 and IMU data before proprioceptive signals are available. Once the robot is walking, legged motion can introduce vibrations, repeated viewpoints, and contact-induced disturbances that degrade exteroceptive odometry [3]. The Jetson Nano also constrains the resolution, frame rate, and algorithm choice.
V. RESOURCES AND TIMELINE

I will use RealSense D415, Jetson Nano, an ESP32 connected via microROS handling peripheral connection to actuators, contact sensors and IMU, ROS 2, rosbag logging, and indoor room-scale test sequences. First, during the week of Mar. 1-7, I will establish the Jetson stack and IMU interface. The following two weeks will implement and benchmark D415 plus IMU odometry. The next two weeks will add SLAM, saved-map localization, and embedded profiling. The final two full weeks prior to delivery of this project will integrate encoder and touch-sensor odometry and perform on-robot validation against the benchmark navigation tasks. The final half week will be used for analysis and final paper / presentation completion.

VI. CONCLUSION
This project is feasible within the remainder of the semester because it separates perception development from late-stage robot completion while preserving a clear transfer path to the final hexapod. The outcome will be an evidencebased recommendation for the odometry, localization, and mapping stack that is most likely to satisfy the embedded navigation requirements of the hexapod.

REFERENCES

[1] Mechatronic Design Spring 2026, “Kinematic/Kinesthetic Dance Robot Specifications,” Version 4.0, course handout.
[2] C. Cadena, L. Carlone, H. Carrillo, Y. Latif, D. Scaramuzza, J. Neira,
I. Reid, and J. J. Leonard, “Past, Present, and Future of Simultaneous Localization and Mapping: Towards the Robust-Perception Age,” IEEE Trans. Robot., vol. 32, no. 6, pp. 1309–1332, 2016.
[3] K. Ebadi et al., “Present and Future of SLAM in Extreme Underground Environments,” arXiv:2208.01787, 2022.

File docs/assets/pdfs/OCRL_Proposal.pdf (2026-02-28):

# Carnegie Mellon University

### Robotics Institute, School of Computer Science – Pittsburgh, PA

Optimal Control and Reinforcement Learning Spring 2026 – Dance Robot

# Proposal

Team: Daniel Gonzalez Lazaro Yechen Zheng
Hongfei Liu
Hongru Liu

Overview

This project develops an optimization-based locomotion controller for a human-carrying hexapod robot intended to navigate a large indoor space reliably and safely. The controller will sit above low-level joint tracking and will generate body-motion and gait commands that achieve consistent waypoint navigation while maintaining stability under payload and respecting actuator limits. Development will be performed primarily in simulation using a URDF/Gazebo model of the robot, with a plan to validate key findings on hardware as the platform is brought up.

The core technical idea is to use modern optimal control and reinforcement learning tools—specifically a sampling-based Model Predictive Control (MPC) approach (MPPI-style) and/or learning-based policy improvements—to optimize gait behavior and command selection in real time. The emphasis is on measurable improvements in task performance (accuracy, time-to-goal, repeatability) while enforcing safety and comfort constraints (tilt margin, smoothness, bounded joint motion/effort).

Goals
1. Establish a baseline locomotion and evaluation framework
- Implement a conservative baseline gait (e.g., ripple or tripod) and a standardized set of navigation tasks in simulation (straight-line travel, curvilinear travel, reverse travel, and turning-in-place).
- Build an automated evaluation harness that logs metrics including: task completion time, path deviation, body roll/pitch peaks, foot slip indicators, contact stability, and actuator saturation events.
2. Implement an optimization-based controller (primary objective)
- Develop a sampling-based MPC controller (MPPI-style) that optimizes a short-horizon action sequence at each control cycle using parallel rollouts and a cost function aligned with navigation and safety objectives.
- Decision variables (initial): commanded body velocity sequence plus a small set of gait parameters (step length, step height, period, duty factor, phase offsets).
- Cost terms:
■ Goal tracking and heading error (progress toward waypoint)
■ Time/efficiency (penalize slow progress)
■ Smoothness/comfort (penalize abrupt accelerations and jerky command changes)
■ Stability margin (penalize excessive tilt or low support margin proxies) ■ Actuation effort (penalize large torque/effort proxies and saturation) Slip/contact penalties (discourage slip and unstable contact patterns)
3. Demonstrate quantifiable improvement over baseline
- Show improvement in at least two of the following under controlled test conditions:
■ Higher success rate across randomized initial conditions and disturbances ■ Lower time-to-goal for fixed accuracy
Reduced peak tilt/roll/pitch and fewer stability violations
■ Reduced actuator saturation and improved energy/effort proxies

- Include ablation results to identify which cost terms (or learned components) drive the most performance benefit.

Timeline
- Weeks 1–2: Simulation bring-up, baseline gait, and automated evaluation harness.
- Weeks 3–4: Implement MPPI/MPC controller and integrate with gait command interface.
- Weeks 5–6: Tune costs/hyperparameters; run robustness tests and ablations vs. baseline.
- Weeks 7–8: Hardware-informed refinement (limits/calibration) and low-speed real tests.

Deliverables

### 1. Controller implementation

- Baseline gait controller and an optimization-based locomotion controller integrated into the robot software stack.
- Configuration files for controller parameters, sampling settings, and cost weights.
2. Reproducible evaluation harness
- Automated scripts to run standardized navigation scenarios in simulation.
- Logged datasets and metrics summaries (tables/plots) for success rate, time-to-goal, tracking error, stability, and saturation.
3. Results package
- A concise technical summary of methods, cost design, tuning process, and quantitative comparisons against baseline.
- Ablation study results and discussion of failure modes and limitations.
4. Demonstration
- Live simulation demo showing repeatable waypoint navigation with stability constraints respected.
- Limited hardware demo showing safe, low-speed execution consistent with simulation trends.

Prior Work / Resources

- Sampling-based MPC / MPPI for robotics control: rollout-based optimization with costs shaped for tracking, smoothness, and constraint handling; widely used for systems with complex/nonlinear dynamics where gradients are difficult or unreliable.
- Legged locomotion control literature on using low-dimensional gait parameterizations, stability proxies (support polygon, tilt margins), and contact-aware cost shaping to produce robust walking behaviors.
- Reinforcement learning for locomotion: policy optimization and residual learning approaches that can improve robustness and adapt to modeling mismatch, typically coupled with safety filters or constraint layers for deployability.
- Simulation-to-real best practices: parameter sweeps, actuator limit modeling, contact/friction sensitivity analysis, and incremental validation using hardware-in-the-loop or single-limb testbeds.

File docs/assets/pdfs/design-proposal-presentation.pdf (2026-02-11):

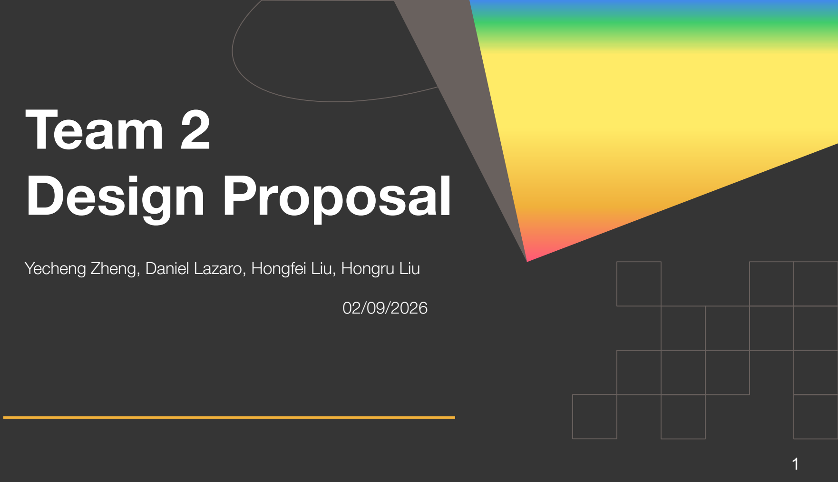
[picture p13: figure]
Team 2 Design Proposal

### Yecheng Zheng, Daniel Lazaro, Hongfei Liu, Hongru Liu

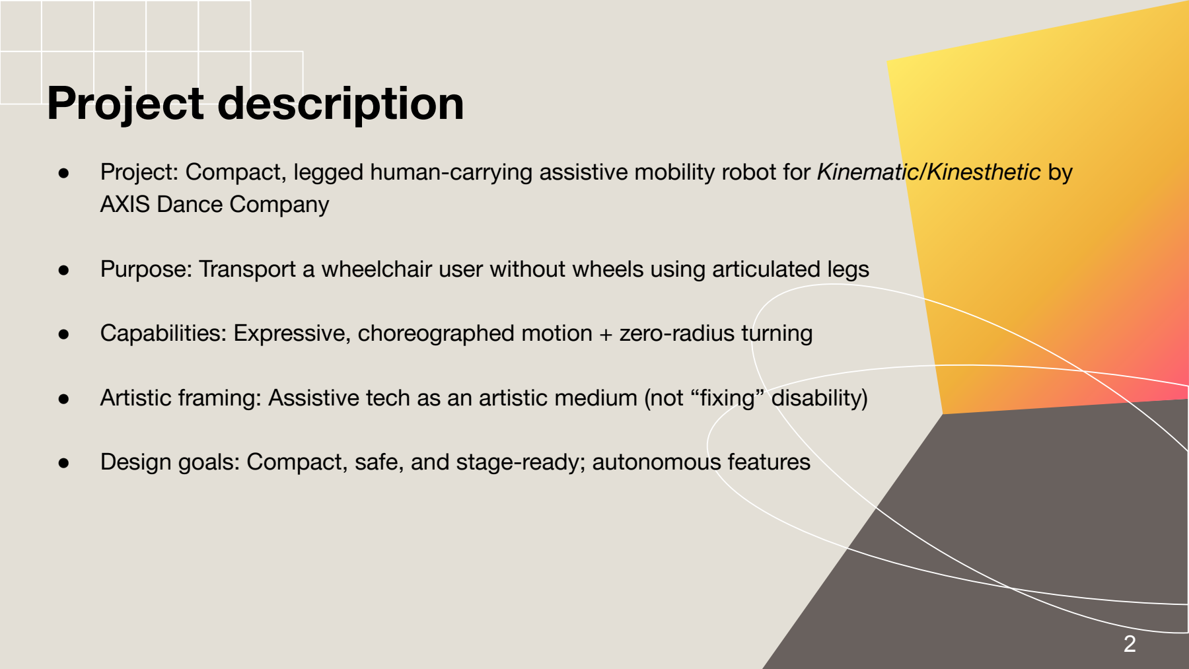
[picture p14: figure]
Project description; AXIS Dance Company

- Project: Compact, legged human-carrying assistive mobility robot for Kinematic/Kinesthetic by

### - Purpose: Transport a wheelchair user without wheels using articulated legs

### - Capabilities: Expressive, choreographed motion + zero-radius turning

### - Artistic framing: Assistive tech as an artistic medium (not “fixing” disability)

### - Design goals: Compact, safe, and stage-ready; autonomous features

# Design requirements

3

### Locomotion & Motion

### Leg-driven locomotion (auxiliary wheels allowed for support)

### Forward / backward motion

### Zero-radius turning (CW & CCW)

### Size, Weight & Payload

### Max footprint: 5’ × 5’

### Rider height: 2–3 ft above ground

### Robot mass ≤ 150 lb

### Payload capacity ≥ 170 lb

### User & Safety

### Seated or cross-legged

### User fully off ground, clear sight

### Safe and stable for live performance

### Performance & Transport

### Navigate to target within 6” in accuracy in < 1 min

### Speed range: 1–4 mph

### Ships in 3’ × 3’ × 3’ case (≤7 parts)

### Fits through 36” door when folded

# Design trade studies

Our Design | Daft Punks | Dancing Queens
Locomotion mechanism | Klann linkage | Fully actuated articulated legs | Fully actuated articulated legs
Actuation per leg | 1 motor drives 2 legs per side | Stepper motor + linear actuator per leg | 2 stepper motors per leg
Gait generation | Mechanically encoded via Klann linkage (continuous motion) | Software-defined tripod gait | Software-defined tripod gait
Actuation | Mechanically coupled | Independently actuated | Independently actuated
Turning | Differential motor speed (tank-style) | Gait modification | Gait modification

# Functional architecture

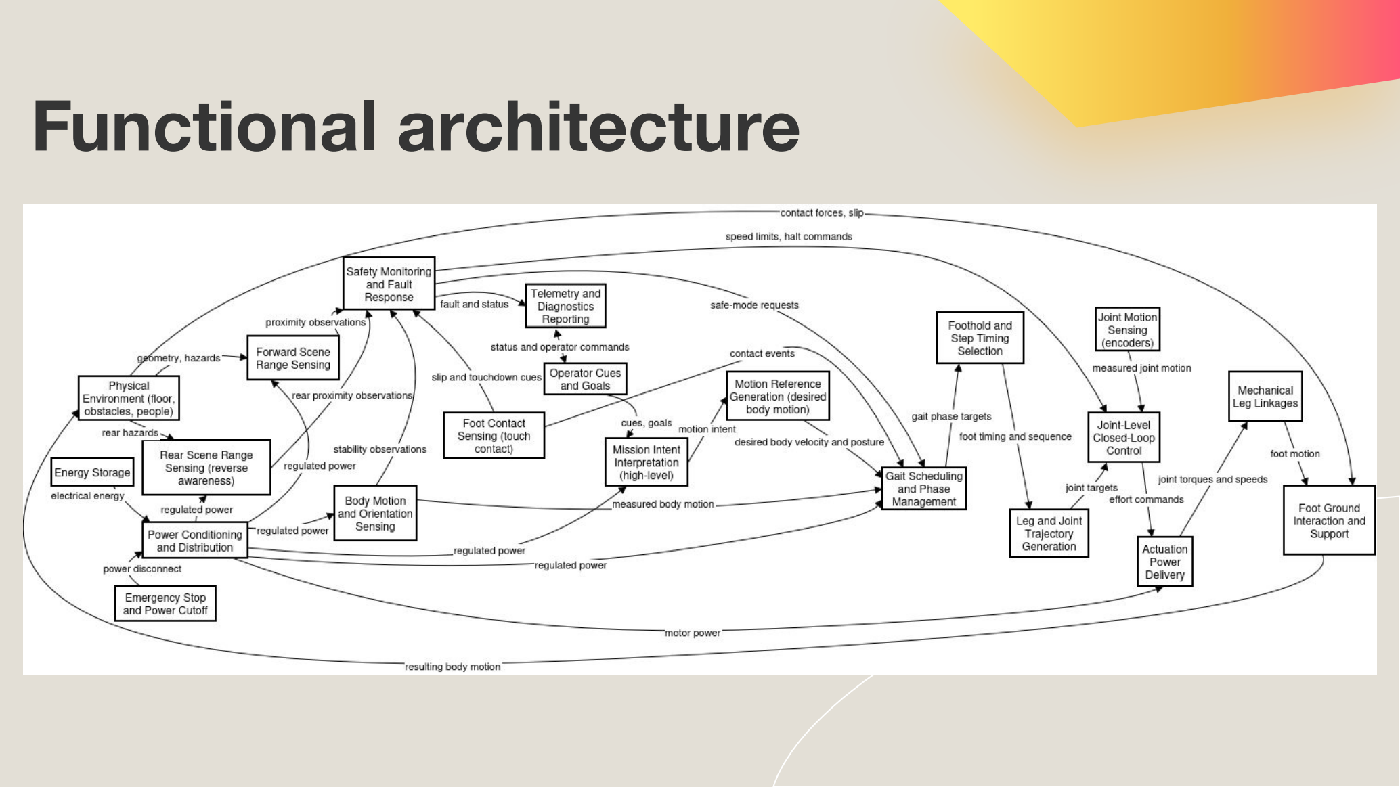
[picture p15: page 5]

# Cyber Physical architecture

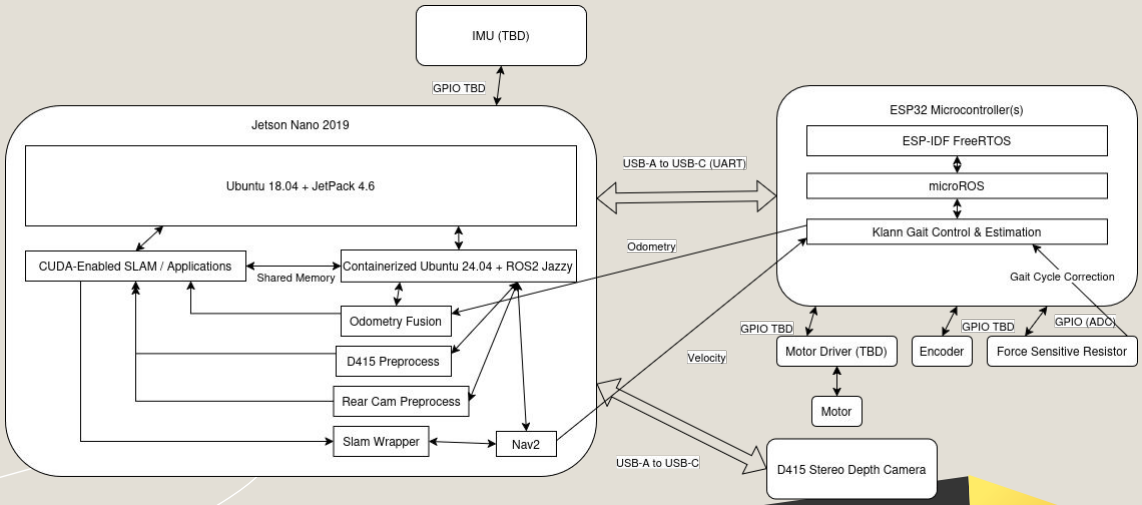
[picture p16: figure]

## System depiction - Overview

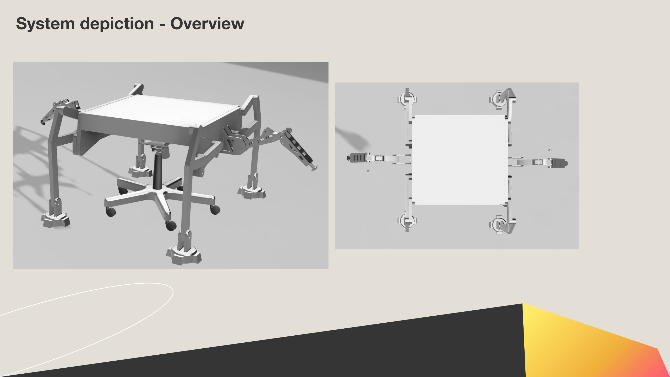
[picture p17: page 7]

## System depiction - Klann Linkage Style Leg

Jensen Linkage | Klann Linkage | CAD Model

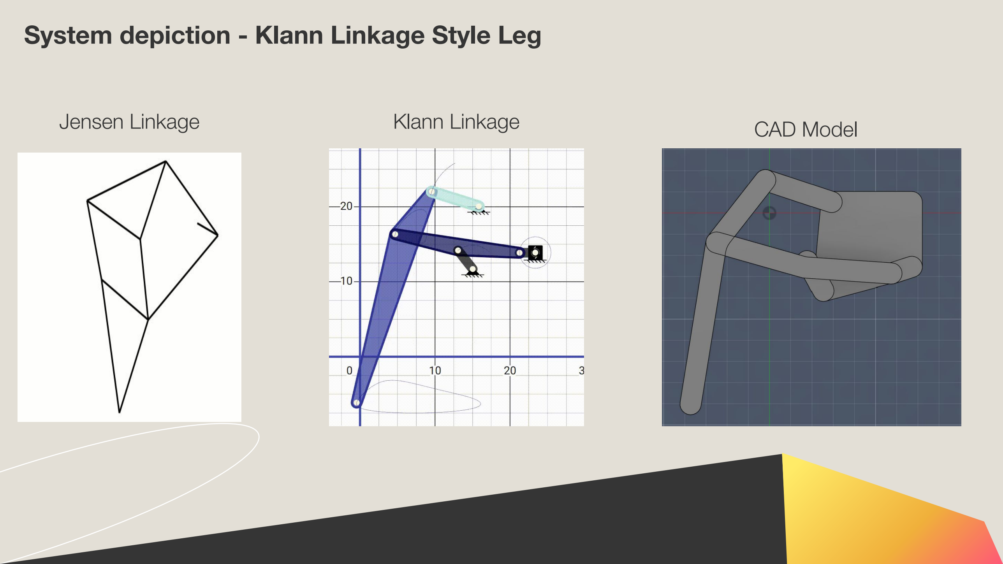
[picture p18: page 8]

## System depiction - Klann Linkage

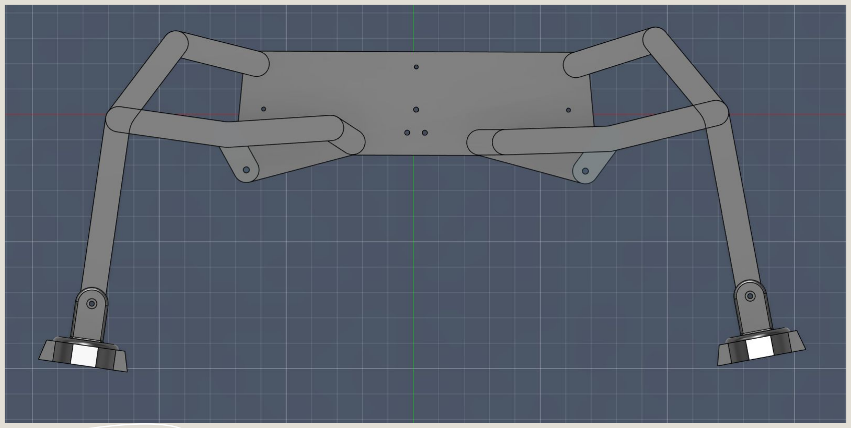
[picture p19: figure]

## System depiction - Side Legs

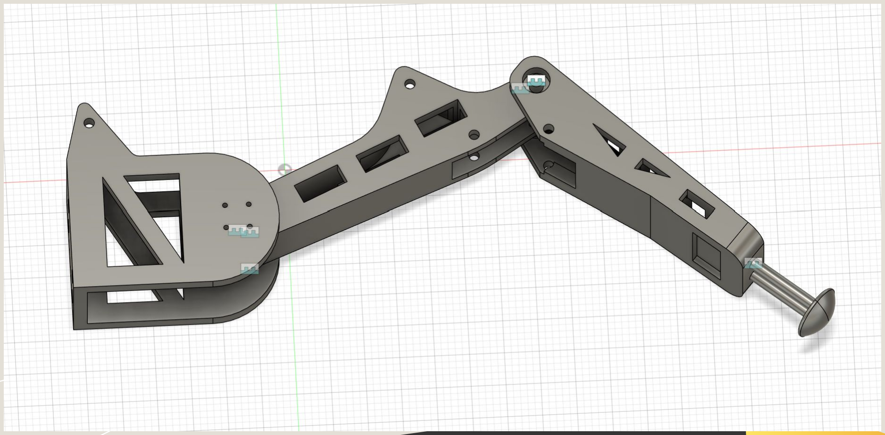
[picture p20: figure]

# Schedule &

# Responsibilities

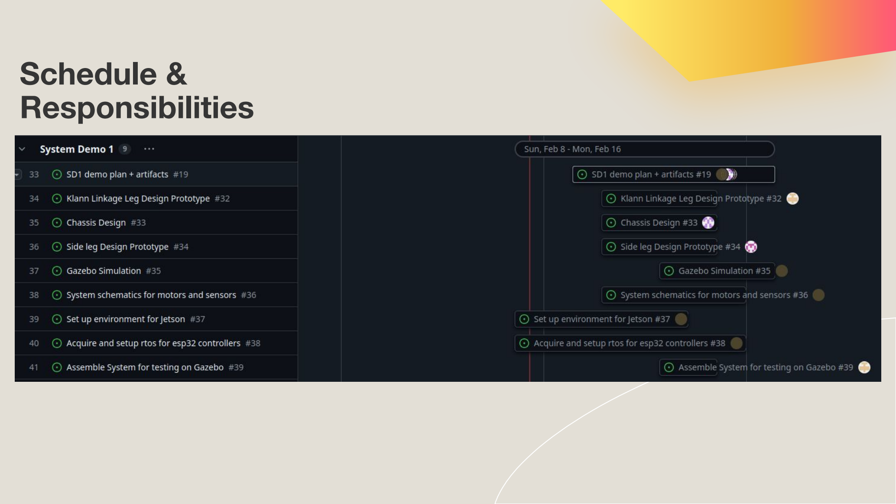
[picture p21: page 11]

# Estimated budget - Mechanical

Item | Description / Notes | Qty | Unit Cost (USD)
DC gear motors (Klann drive) | Rotary motors driving Klann crank shafts | 2–4 | $40 – $80
Motor mounting brackets | Motor-to-frame mounts | 2–4 | $15 – $50
Shaft couplers | Motor-to-crank shaft couplers | 2–4 | $10 – $30
Crank shafts | Steel or aluminum shafts | 2–4 | $15 – $50
Pillow block / radial bearings | Support crank shafts | 4–8 | $10 – $40
Shaft collars | Axial shaft retention | 6–12 | $5 – $15
Klann linkage plates | Aluminum / G10 link sets | 4 sets | $25 – $120
Shoulder bolts / joint pins | Klann pivot joints (M5–M8) | 4 sets | $15 – $60
Bearings / bushings | Flanged bearings or bronze bushings | 4 sets | $20 – $80
Spacers & washers | Aluminum / nylon spacers | 4 sets | $5 – $20
Klann foot pads | Rubber / TPU feet | 4 | $5 – $25
Klann leg mounting brackets | Leg-to-frame interface | 4 | $10 – $50
Linear actuators (motor inside) | 100–200 mm stroke, 300–1000 N | 2 | $40 – $250
Clevis / rod ends | Actuator end joints | 4 | $10 – $40
Actuator mounting brackets | Frame & leg mounts | 2 sets | $20 – $60

Estimated budget - Cont.
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

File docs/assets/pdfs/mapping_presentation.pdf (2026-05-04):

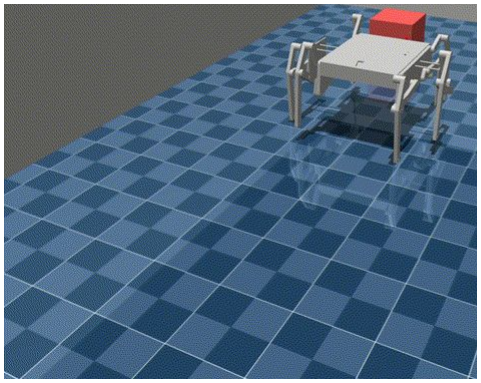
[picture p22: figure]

# Dance Hexapod Navigation

## Daniel González Lázaro

4/20/2026

## I am controlling a hexapod to achieve curvilinear tripod navigation with strict hardware constraints

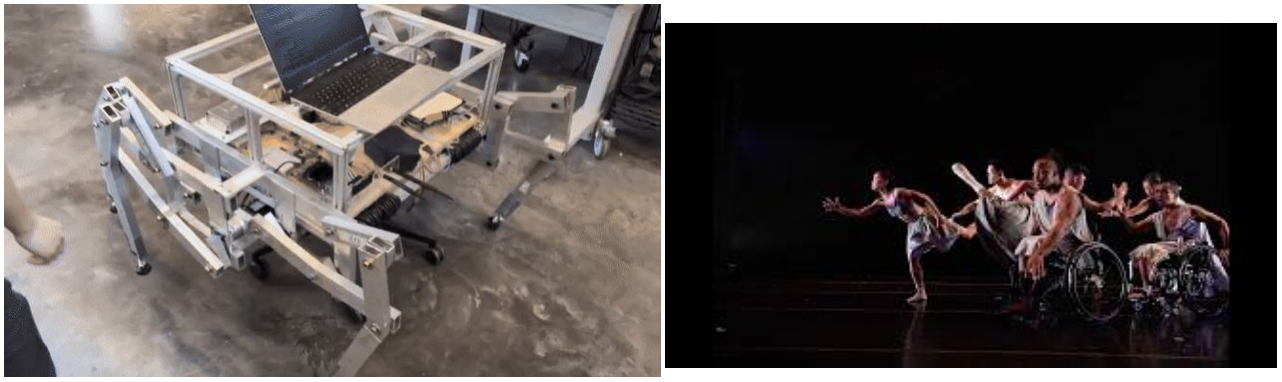
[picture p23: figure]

The robot must achieve navigation goals within 6'' error tolerance in varying light, occlusion environments without powered/encoding support wheels

## Along with tuned control, linkage kinematics have to be modeled in order to estimate body odometry from drifting encoder measurements

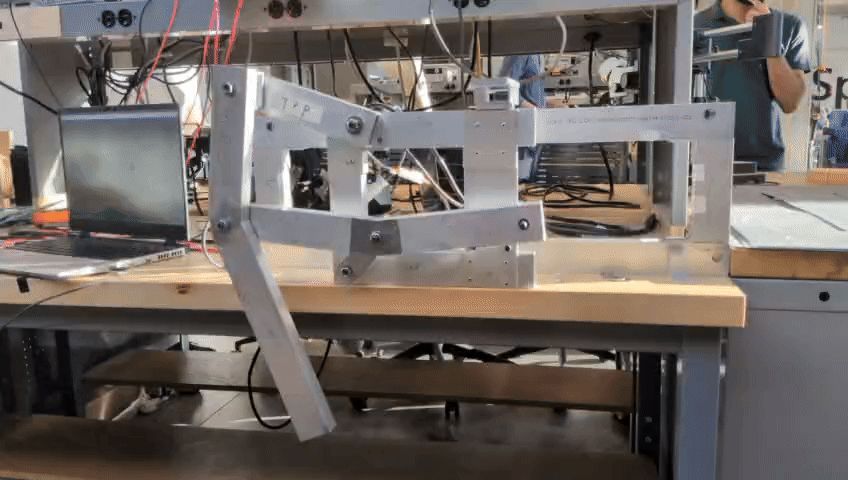
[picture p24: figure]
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

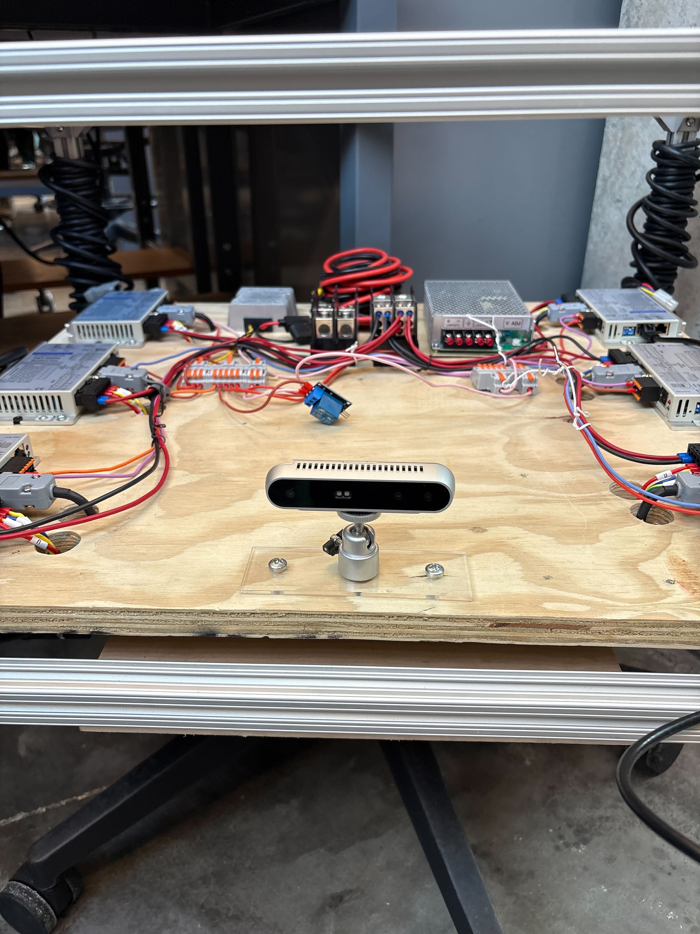
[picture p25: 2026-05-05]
docs/assets/hardware/mainboard_in_progress.jpg

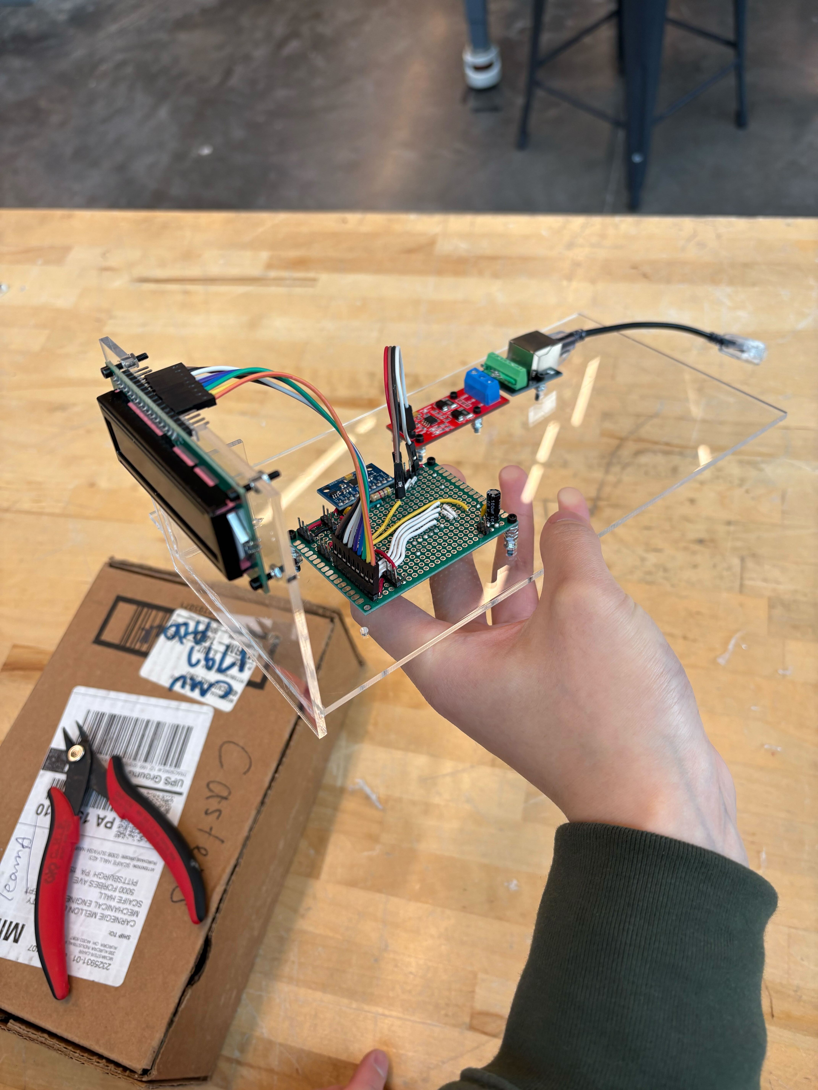
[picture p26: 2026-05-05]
docs/assets/hardware/pcb_mount_prototype.jpg

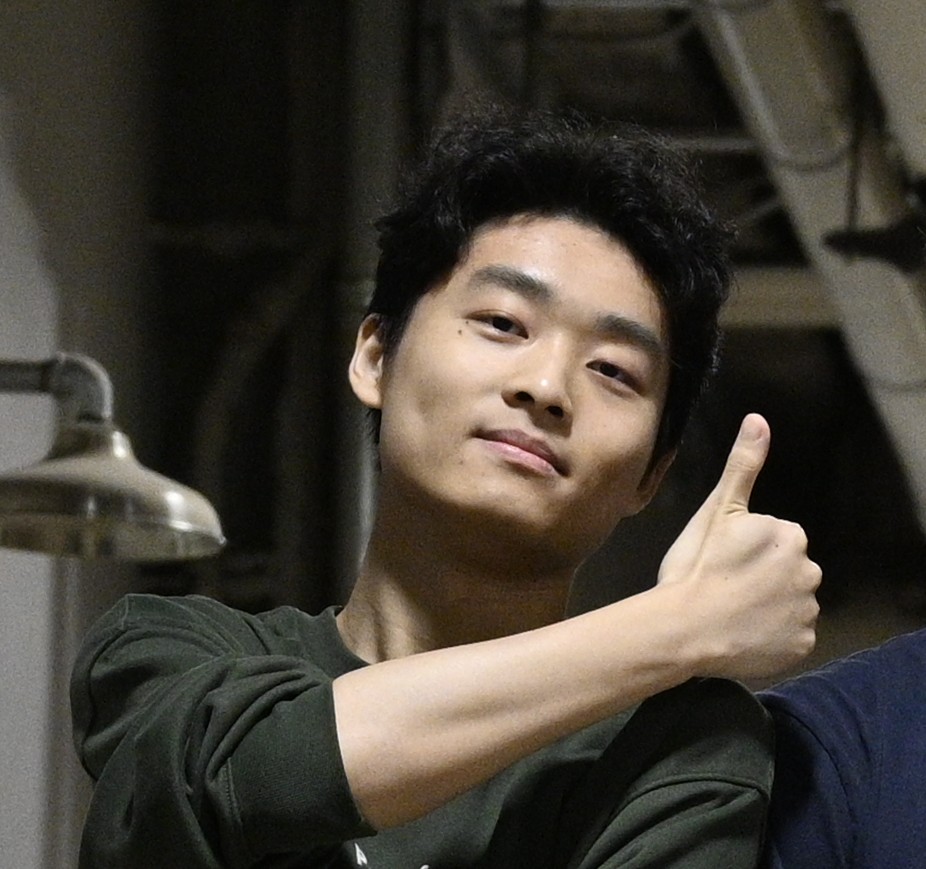
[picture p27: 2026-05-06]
docs/assets/img/Hongfei_Liu.jpg

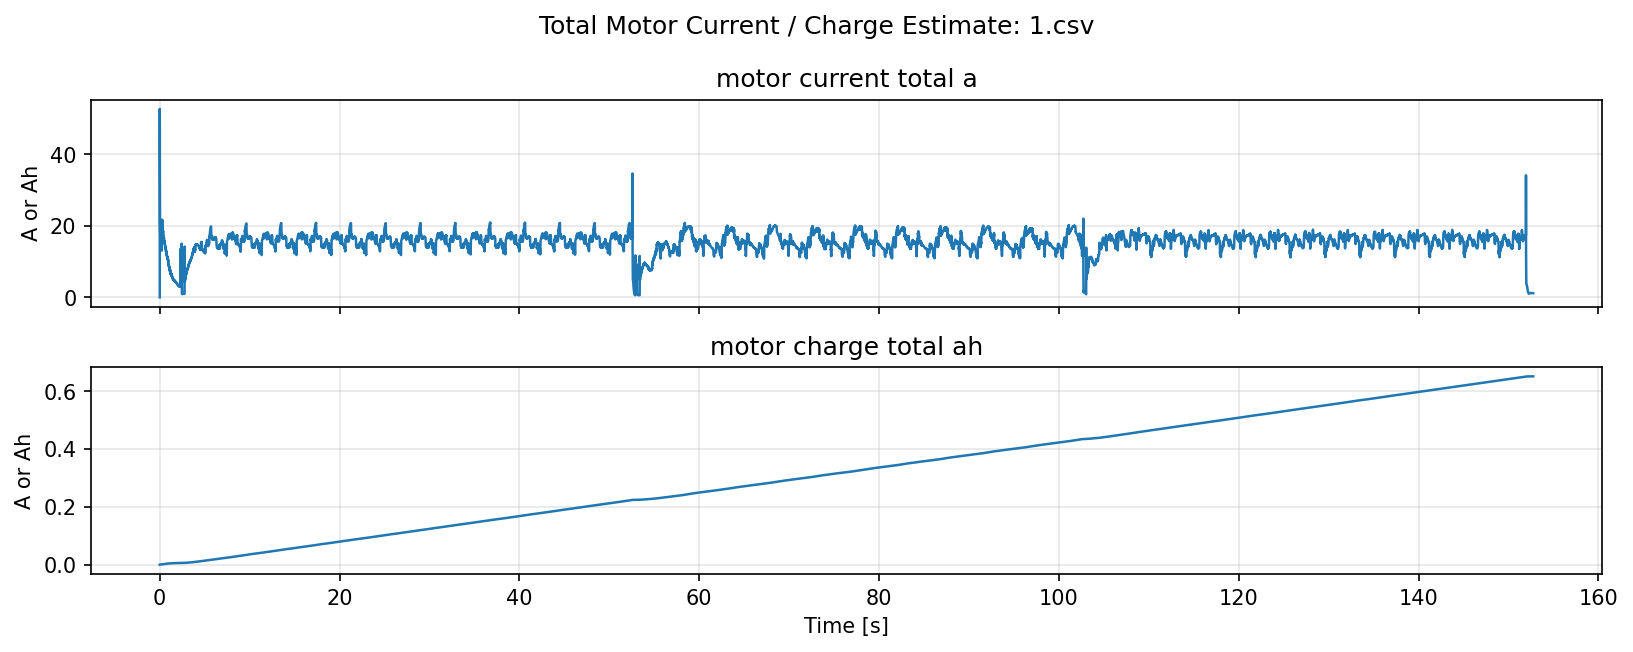
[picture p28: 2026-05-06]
docs/assets/software/mujoco_powerdraw_estimation_graph.jpg

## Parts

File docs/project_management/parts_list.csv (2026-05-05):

Item Name | Link | Vendor | Qty | Price | Budget category
Single Four Slot Rails 1" x 1" (700mm) |  | Final report Table 4 |  | $101.99 | standard 1000 allowance
Single Four Slot Rails 1" x 1" (670mm) |  | Final report Table 4 | 2 | $28.16 | standard 1000 allowance
10, 20, & 25 Series 2 Hole - 18mm Slotted Inside Corner Bracket with Dual Support |  | Final report Table 4 | 10 | $12.70 | standard 1000 allowance
10 Series M6 Standard Slide-in T-Nut |  | Final report Table 4 | 10 | $16.10 | standard 1000 allowance
M6 Slide-in Economy T-Nut Block |  | Final report Table 4 | 10 | $5.30 | standard 1000 allowance
20pcs 10 Extruded Aluminum Corner with T Slide Nuts Bolts |  | Final report Table 4 | 1 | $20.88 | standard 1000 allowance
Single Four Slot Rails 1" x 1" (678mm) |  | Final report Table 4 | 2 | $28.42 | standard 1000 allowance
1" x 1" x 3/ " HOT ROLLED BAR SIZE ANGLE ASTM A36 （12"） 16 |  | Final report Table 4 | 1 | $6.82 | standard 1000 allowance
1" x 1" x ¼" ANGLE 6061-T6 ASTM B308 (12") |  | Final report Table 4 | 1 | $6.33 | standard 1000 allowance
2" x 1" x ⅛" WALL RECTANGULAR TUBE 6061-T6 |  | Final report Table 4 | 10' | $82.20 | standard 1000 allowance
6061 Aluminum Bar ⅛" Thick x 3" Wide |  | Final report Table 4 | 2' | $11.44 | standard 1000 allowance
Mesh Office Chair Height Adjustable 400 lbs |  | Final report Table 4 | 1 | $69.99 | standard 1000 allowance
1" x 1¼" FLAT 6061-T6511 ASTM B221 |  | Final report Table 4 | 5' | $48.95 | standard 1000 allowance
1" x 2½" FLAT 6061-T6511 ASTM B221 |  | Final report Table 4 | 2' | $48.72 | standard 1000 allowance
Alloy Steel Shoulder Screw ½" Diameter, 2¼" Length, ⅜"-16 Thread |  | Final report Table 4 | 6 | $23.88 | standard 1000 allowance
1½" x 1½" x ⅛" ANGLE 6061-T6 ASTM B308 |  | Final report Table 4 | 2' | $11.36 | standard 1000 allowance
2" x 1" x ⅛" WALL RECTANGULAR TUBE 6061-T6 |  | Final report Table 4 | 6' | $46.08 | standard 1000 allowance
Oil-Embedded 863 FeCu Sleeve Bearing ½" Diameter ⅝" Housing, 1" Long |  | Final report Table 4 | 22 | $36.08 | standard 1000 allowance
Oil-Embedded 863 FeCu Sleeve Bearing ½" Diameter, ⅝" Housing, ¾" Long |  | Final report Table 4 | 6 | $6.24 | standard 1000 allowance
Alloy Steel Shoulder Screw, ½" Diameter, 3" Length, ⅜"-16 Thread |  | Final report Table 4 | 5 | $22.90 | standard 1000 allowance
Alloy Steel Shoulder Screw ½" Diameter, 1¾" Length, ⅜"-16 Thread |  | Final report Table 4 | 6 | $21.78 | standard 1000 allowance
2" X 1" X ⅛" WALL RECTANGULAR TUBE 6061-T6 |  | Final report Table 4 | 20' | $133.60 | standard 1000 allowance
Oil-Embedded 863 FeCu Sleeve Bearing ½ " Diameter, ⅝" Housing, 1" Long |  | Final report Table 4 | 33 | $54.12 | standard 1000 allowance
Oil-Embedded 863 FeCu Sleeve Bearing ½" Diameter, ⅝" Housing, ¾" Long |  | Final report Table 4 | 6 | $6.24 | standard 1000 allowance
6061 Aluminum Bar ⅛" Thick x 3" Wide |  | Final report Table 4 | 1.5' | $9.36 | standard 1000 allowance
Alloy Steel Shoulder Screw ½" Diameter, 1-¾" Length, ⅜"-16 Thread |  | Final report Table 4 | 6 | $21.78 | standard 1000 allowance
Alloy Steel Shoulder Screw ½" Diameter, 2¼ " Length, ⅜"-16 Thread |  | Final report Table 4 | 6 | $23.88 | standard 1000 allowance
Alloy Steel Shoulder Screw, ½" Diameter, 2" Length, ⅜"-16 Thread |  | Final report Table 4 | 1 | $4.25 | standard 1000 allowance
Alloy Steel Cup-Tip Set Screw M5 x 0.8 mm, 45 mm Long |  | Final report Table 4 | 5 | $5.96 | standard 1000 allowance
Low-Strength Steel Hex Nuts M5 x 0.8 mm |  | Final report Table 4 | 100 | $2.50 | standard 1000 allowance
2" X 1" X .125 WALL RECTANGULAR TUBE 6061-T6 |  | Final report Table 4 | 6' | $46.08 | standard 1000 allowance
2" X 1" X .125 WALL RECTANGULAR TUBE 6061-T6 |  | Final report Table 4 | 2' | $24.67 | standard 1000 allowance
6061 Aluminum Bar, 5/ " Thick x 2" Wide 16 |  | Final report Table 4 | 3' | $24.19 | standard 1000 allowance
6061 Aluminum Bar, ⅛" thick 3" wide |  | Final report Table 4 | 4.5' | $26.52 | standard 1000 allowance
6061 Aluminum Bar 1" Thick x 2½" Wide |  | Final report Table 4 | 1' | $0.00 | standard 1000 allowance
J-B Weld Steel Reinforced Epoxy |  | Final report Table 4 | 1 | $12.38 | standard 1000 allowance
6061 Aluminum 90 Degree Angle, ⅛" Thickness, 1½" Outside Height |  | Final report Table 4 | 2' | $0.00 | standard 1000 allowance
DSY Series 400W RS485 DC Servo Motor |  | Final report Table 5 | 6 | $742.03 | 2500 motor stipend
TG Series 60mm 50:1 Planetary Gearbox |  | Final report Table 5 | 6 | $466.42 | 2500 motor stipend
52V 25Ah high-current Li-ion battery |  | Final report Table 5 | 1 | $745.99 | 2500 motor stipend
52v 3a xt60 battery charger |  | Final report Table 5 | 1 | $69.99 | 2500 motor stipend
Nema 23 Bracket for Spur Gearbox Geared Stepper Motor |  | Final report Table 5 | 6 | $36.90 | 2500 motor stipend
2.1mm 6' j25 barrel jack connector w/ cable |  | Final report Table 6 | 1 | $6.06 | circuit contributions
5V 50W DC/DC converter |  | Final report Table 6 | 1 | $31.70 | circuit contributions
1.35mm jack connector with cable |  | Final report Table 6 | 1 | $2.12 | circuit contributions
AEV250 500A DC contactor |  | Final report Table 6 | 1 | $78.58 | circuit contributions
XT90 Connector set |  | Final report Table 6 | 1 | $3.9 | circuit contributions
Chassis mount 10Ω 100W resistor |  | Final report Table 6 | 6 | $72.42 | circuit contributions
Auto Fuse holder |  | Final report Table 6 | 1 | $13.12 | circuit contributions
60A 58VDC fuse |  | Final report Table 6 | 1 | $4.7 | circuit contributions
cat6 1' cable |  | Final report Table 6 | 4 | $3.97 | circuit contributions
18awg Silicone wire |  | Final report Table 6 | 50' | $13.98 | circuit contributions
WT901 |  | Final report Table 6 | 1 | $33.9 | circuit contributions
200VDC solid state relays |  | Final report Table 6 | 2 | $16.99 | circuit contributions
40pc 10cm f/f dupont wire |  | Final report Table 6 | 1 | $4.59 | circuit contributions
intel 8265 |  | Final report Table 6 | 1 | $21.19 | circuit contributions
esp32 |  | Final report Table 6 | 1 | $6.67 | circuit contributions
rj45 breakout board |  | Final report Table 6 | 1 | $4.50 | circuit contributions
TTY to RS485 adapter |  | Final report Table 6 | 1 | $4.99 | circuit contributions
10awg silicone wire |  | Final report Table 6 | 2' | $8.44 | circuit contributions
2 circuit 175A 1 in 6 out distribution block |  | Final report Table 6 | 1 | $73.39 | circuit contributions
2 circuit 175A 1 in 4 out distribution block |  | Final report Table 6 | 1 | $41.86 | circuit contributions
small connector distribution blocks |  | Final report Table 6 | 26 | $14.55 | circuit contributions
24V 240W DC/DC converter |  | Final report Table 6 | 1 | $24.99 | circuit contributions
powered usb hub |  | Final report Table 6 | 1 | $19.99 | circuit contributions

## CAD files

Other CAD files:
docs/assets/designs/linkage_schematic.dwg

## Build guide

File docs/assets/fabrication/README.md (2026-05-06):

# Fabrication assets

Place chassis, raw stock, linkage, crank, elbow, and machining media here:

- raw_aluminum.jpg
- building_chassis.jpg
- linkage_bar_assembly.jpg
- single_linkage_running.mp4
- first_assembled_linkage.jpg
- finished_elbows.jpg
- elbow_drillpress.jpg
- crank_finished.jpg
- cnc_elbow.webm

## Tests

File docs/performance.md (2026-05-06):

---
title: "System Performance"
---

{% include nav.html %}
{% include page-assets.html cards=true media_gallery=true model_viewer=true %}

<div class="t2-card">
  <h2>System Performance</h2>
  <p class="t2-sub">Measured class-final outcomes, motion evidence, odometry calibration status, and remaining limitations.</p>
  <p>
    The final class system met the central feasibility goals: it carried rider-scale payloads, produced body-displacing legged locomotion, operated quietly, and demonstrated odometry/navigation behavior at the required order of accuracy. These results validate the approach for the class project, but they are not yet production-stage certification for performance use.
  </p>
  <div class="t2-metric-grid">
    <div class="t2-metric"><b>Payload</b><span>&gt;200 lb supported/transported without structural failure</span></div>
    <div class="t2-metric"><b>Unloaded speed</b><span>~0.7 m/s forward/backward</span></div>
    <div class="t2-metric"><b>Human-payload speed</b><span>~0.44 m/s with rider</span></div>
    <div class="t2-metric"><b>Navigation tolerance</b><span>6 in target achieved in straight-line odometry/navigation tests after calibration</span></div>
  </div>
</div>

<div class="t2-card" id="motion-evidence">
  <h2>Motion Evidence</h2>
  <div class="t2-video">
    <iframe
      src="https://www.youtube-nocookie.com/embed/3NwqyyyJGHU?rel=0"
      title="Final hexapod walking demonstration"
      frameborder="0"
      allow="accelerometer; autoplay; clipboard-write; encrypted-media; gyroscope; picture-in-picture; web-share"
      allowfullscreen>
    </iframe>
  </div>
  <div class="t2-links">
    <a class="t2-linkbtn" href="https://www.youtube.com/watch?v=3NwqyyyJGHU" target="_blank" rel="noreferrer">Watch on YouTube</a>
  </div>
</div>

<div class="t2-card" id="requirements">
  <h2>Requirements Compliance</h2>
  <div class="t2-table-wrap">
    <table class="t2-table">
      <thead>
        <tr><th>Requirement</th><th>Metric</th><th>Test method</th><th>Result</th><th>Status</th></tr>
      </thead>
      <tbody>
        <tr><td>Leg-initiated locomotion</td><td>Robot body displacement from Klann legs</td><td>Physical walking tests</td><td>Final robot achieved forward/backward body-displacing locomotion.</td><td>Pass</td></tr>
        <tr><td>Carry rider-scale payload</td><td>170 lb required; 150 lb demo payload</td><td>Loaded physical tests</td><td>Transported payloads exceeding 170 lb; final report notes stable operation beyond 200 lb.</td><td>Pass</td></tr>
        <tr><td>Navigation/odometry tolerance</td><td>Reach designated point within 6 in</td><td>Tape-measured calibration and teleop/odometry trials</td><td>After final sign, mirror, and scale corrections, straight-line odometry was within tolerance.</td><td>Pass for straight-line class-final tests</td></tr>
        <tr><td>Speed/time feasibility</td><td>10 ft course within task time windows</td><td>Measured locomotion speed</td><td>~0.7 m/s unloaded and ~0.44 m/s with rider, sufficient for 10 ft tasks if controlled.</td><td>Pass</td></tr>
        <tr><td>Onboard compute</td><td>No laptop in final machine</td><td>Jetson Nano + ESP32 deployment</td><td>Jetson runs host SLAM and containerized ROS; ESP32 handles power/motor control.</td><td>Pass</td></tr>
        <tr><td>Mapping and waypoint support</td><td>Occupancy grid and Nav2 goal path</td><td>D415 + ORB-SLAM2 + virtual scan + slam_toolbox</td><td>ROS stack produces map/odom/scan products and operator map interface for goal placement.</td><td>Partial/pass for class-final integration</td></tr>
        <tr><td>Runtime</td><td>30 minutes onboard power</td><td>Battery operation during testing</td><td>52 V 25 Ah pack supported extended multi-session testing according to the final report.</td><td>Pass qualitatively; longer instrumented endurance test recommended</td></tr>
        <tr><td>Impact/drop robustness</td><td>25 lb dropped from 5 ft</td><td>Formal drop test</td><td>Not performed.</td><td>Not verified</td></tr>
      </tbody>
    </table>
  </div>
</div>

<div class="t2-card" id="odometry-mapping-results">
  <h2>Odometry and Mapping Results</h2>
  <p>
    The strongest software result is that encoder-plus-linkage odometry became useful enough to meet the class navigation tolerance after calibration. The host observer unwraps raw 17-bit single-turn motor encoder counts, converts them through the 50:1 gearbox to output crank phase, evaluates measured Klann geometry, and solves a stance-foot no-slip least-squares body twist.
  </p>
  {% include asset-item.html key="videos" index=6 layout="wide" caption="ORB-SLAM odometry test animation showing the host-native SLAM process feeding the ROS 2 bridge and visualization path." %}
  <p>
    In the final mapping report, a 73 in physical straight-line trial initially produced about 0.851 m of uncalibrated kinematic forward motion. The final configuration applies a kinematic mirror and a body-twist scale of 2.1786 in x/y. A separate ORB/scan scale calibration is applied consistently to ORB pose, sparse points, and virtual scan ranges.
  </p>
  <p class="t2-note">
    These values are empirical calibration parameters, not universal constants. Additional forward, reverse, yaw, payload, and stage-surface trials are required before the odometry model should be treated as production-calibrated.
  </p>
</div>

<div class="t2-card" id="remaining-limits">
  <h2>Known Limitations</h2>
  <ul>
    <li>RS485 throughput constrains control rate and encoder polling. Higher RPM increases single-turn wrap ambiguity.</li>
    <li>FSR foot-contact signals were not yet reliable enough to gate odometry; phase-derived stance confidence is used instead.</li>
    <li>Foot slip and surface compliance can bias no-slip kinematic odometry.</li>
    <li>ORB-SLAM2 CUDA is useful but remains a constrained Jetson deployment requiring process supervision and fallback odometry.</li>
    <li>Auxiliary support elements remain part of the final physical stability strategy; the platform is not yet a purely leg-only load-bearing walker under all conditions.</li>
    <li>Stage deployment still requires longer reliability trials, calibrated stopping behavior, lighting/occlusion tests, and rehearsal-specific maps.</li>
  </ul>
</div>

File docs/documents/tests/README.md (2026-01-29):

[Home](index.md) •
[Problem](problem.md) •
[Design](design.md) •
[Implementation](implementation.md) •
[Performance](performance.md) •
[Project Management](management.md) •
[Media](media.md) •
[Documents](documents.md) •
[Team](team.md)

# Component Testing & Experiment Results

Record how you tested components and what you observed. Include plots/tables and links to raw logs.

## Suggested structure
- `YYYY-MM-DD_<short_title>.pdf` or `.md`
- Keep files small; link to external storage for huge videos/logs.

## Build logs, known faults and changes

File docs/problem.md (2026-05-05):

---
title: "Problem Description"
---

{% include nav.html %}
{% include page-assets.html cards=true media_gallery=true %}

{% include problem-cards.html %}

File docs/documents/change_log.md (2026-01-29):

[Home](index.md) •
[Problem](problem.md) •
[Design](design.md) •
[Implementation](implementation.md) •
[Performance](performance.md) •
[Project Management](management.md) •
[Media](media.md) •
[Documents](documents.md) •
[Team](team.md)

# Change Log (Template)

Use this as a living log of what changed and why.

| Date | Artifact / Page | What changed | Why |
|---|---|---|---|
| 2026-01-29 | Site template | Initial scaffold created | Start documentation early |

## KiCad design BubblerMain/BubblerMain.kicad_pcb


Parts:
C13: 0.1uF; C_1206_3216Metric_Pad1.33x1.80mm_HandSolder
C19: 1000uF; CP_Elec_10x10
J2, J3, J4, J5: Conn_01x03_Pin; JST_XH_B3B-XH-AM_1x03_P2.50mm_Vertical
R9, R10, R11, R12: 330; R_1206_3216Metric_Pad1.30x1.75mm_HandSolder
U1: 74AHCT125; SOIC-14_3.9x8.7mm_P1.27mm; LCSC C2675672

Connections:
+5V: C13.1, C19.1, J2.3, J3.3, J4.3, J5.3, U1.14 (VCC); also elsewhere on the board
GND1: C13.2, C19.2, J2.1, J3.1, J4.1, J5.1, U1.1, U1.4, U1.7 (GND), U1.10, U1.13; also elsewhere on the board
LED1 Signal: U1.2; also elsewhere on the board
LED2 Signal: U1.5; also elsewhere on the board
LED3 Signal: U1.9; also elsewhere on the board
LED4 Signal: U1.12; also elsewhere on the board
unnamed: J2.2, R9.1
unnamed: J3.2, R10.1
unnamed: J4.2, R11.1
unnamed: J5.2, R12.1
unnamed: R9.2, U1.3
unnamed: R10.2, U1.6
unnamed: R11.2, U1.8
unnamed: R12.2, U1.11


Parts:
5V2: TestPoint; TestPoint_Pad_2.0x2.0mm
C1: 220uf; CP_Elec_10x10
C2, C3: 10uf; C_1206_3216Metric_Pad1.33x1.80mm_HandSolder
C4: 0.1uF; C_1210_3225Metric_Pad1.33x2.70mm_HandSolder
C5, C6: 22uF; C_1210_3225Metric_Pad1.33x2.70mm_HandSolder
C7: 0.1uF; C_1206_3216Metric_Pad1.33x1.80mm_HandSolder
D1: SMAJ13A; D_SMA
F1: Polyfuse; Fuse_1812_4532Metric
GND1: TestPoint; TestPoint_Pad_2.0x2.0mm
J1: Conn_01x04_Pin; JST_XH_B2B-XH-AM_1x02_P2.50mm_Vertical
L1: 3.3uH; IND_SPM6530T-3R3M; PARTREV N/A; LCSC C76856
Q1: DMP3013SFV; Diodes_PowerDI3333-8; LCSC C264098
R1, R2: 100k; R_1206_3216Metric_Pad1.30x1.75mm_HandSolder
R5: 54.9k; R_1206_3216Metric_Pad1.30x1.75mm_HandSolder
R6: 10k; R_1206_3216Metric_Pad1.30x1.75mm_HandSolder
U9: TPS565201DDCR; SOT95P280X110-6N; LCSC C327676

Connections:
+5V: 5V2.1, C5.1, C6.1, L1.2, R5.1; also elsewhere on the board
/Power Block/BAT+: F1.2, J1.1
/Power Block/Fuse-Pol: F1.1, Q1.5 (D)
GND1: C1.2, C2.2, C3.2, C5.2, C6.2, C7.2, D1.1 (A1), GND1.1, J1.2, R1.2, R6.2, U9.1 (GND); also elsewhere on the board
Motor Power: C1.1, C2.1, C3.1, C7.1, D1.2 (A2), Q1.1 (S), Q1.2 (S), Q1.3 (S), R2.1, U9.3 (VIN); also elsewhere on the board
unnamed: Q1.4 (G), R1.1
unnamed: R2.2, U9.5 (EN)
unnamed: C4.1, L1.1, U9.2 (SW)
unnamed: C4.2, U9.6 (VBST)
unnamed: R5.2, R6.1, U9.4 (VFB)

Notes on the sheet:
Output Filter
Input Filter
Spike Protection
Reverse Polarity Protection


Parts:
3.3V1, 5V1: LED; LED_1206_3216Metric_Pad1.42x1.75mm_HandSolder
3v3: TestPoint; TestPoint_Pad_2.0x2.0mm
C8, C21: 1uF; C_1206_3216Metric_Pad1.33x1.80mm_HandSolder
C9, C22: 22uF; C_1210_3225Metric_Pad1.33x2.70mm_HandSolder
C20: 0.1uF; C_1206_3216Metric_Pad1.33x1.80mm_HandSolder
D2, D3: SS14; D_SMA
FB1: 600; L_1206_3216Metric
J8: USB_C_Receptacle; USB_C_Receptacle_HCTL_HC-TYPE-C-16P-01A
J9: Conn_01x08_Pin; PinHeader_1x08_P2.54mm_Vertical
J12: Conn_01x08_Pin; PinHeader_1x04_P2.54mm_Vertical
MOTOR1: LED; LED_1206_3216Metric_Pad1.42x1.75mm_HandSolder
R16, R17: 5.1k; R_1206_3216Metric_Pad1.30x1.75mm_HandSolder
R18, R19: 10k; R_1206_3216Metric_Pad1.30x1.75mm_HandSolder
R20, R22: 1.5k; R_1206_3216Metric_Pad1.30x1.75mm_HandSolder
R21, R23, R26: 680; R_1206_3216Metric_Pad1.30x1.75mm_HandSolder
SW1, SW2: SW_Push; SW_SPST_PTS645Sx43SMTR92
SW3: LED; LED_1206_3216Metric_Pad1.42x1.75mm_HandSolder
U4: ESP32-S3-WROOM-1; ESP32-S3-WROOM-2; LCSC C2913198
U5: AP2112K-3.3; SOT-23-5; LCSC C23380830
U6: USBLC6-2SC6; SOT-23-6; LCSC C2827654
USB1: LED; LED_1206_3216Metric_Pad1.42x1.75mm_HandSolder

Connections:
+3V3: 3v3.1, C20.1, C22.1, J12.3, R18.1, R19.1, R21.1, U4.2 (3V3), U5.5 (VOUT); also elsewhere on the board
+5V: FB1.1, J12.4; also elsewhere on the board
/ESP32/A6: J8.A6 (D+), J8.B6 (D+), U6.4 (I/O2)
/ESP32/A7: J8.A7 (D-), J8.B7 (D-), U6.6 (I/O1)
/ESP32/GPIO8: J9.1, U4.12 (IO8)
/ESP32/GPIO9: J9.2, U4.17 (IO9)
/ESP32/GPIO10: J9.3, U4.18 (IO10)
/ESP32/GPIO11: J9.4, U4.19 (IO11)
/ESP32/GPIO12: J9.5, U4.20 (IO12)
/ESP32/GPIO13: J9.6, U4.21 (IO13)
/ESP32/GPIO14: J9.7, U4.22 (IO14)
/ESP32/GPIO21: J9.8, U4.23 (IO21)
/ESP32/SW_LED: R23.1, U4.25 (IO48)
/ESP32/VBUS: D2.2 (A), J8.A4 (VBUS), J8.A9 (VBUS), J8.B4 (VBUS), J8.B9 (VBUS), R22.1, U6.5 (VBUS)
GND1: 3.3V1.1 (K), 5V1.1 (K), C8.2, C9.2, C20.2, C21.2, C22.2, J8.A1 (GND), J8.A12 (GND), J8.B1 (GND), J8.B12 (GND), J12.1, MOTOR1.1 (K), R16.2, R17.2, SW1.1, SW2.2, SW3.1 (K), U4.1 (GND), U4.40 (GND), U4.41 (GND), U5.2 (GND), U6.2 (GND), USB1.1 (K); also elsewhere on the board
I2S_SCK: U4.9 (IO16); also elsewhere on the board
I2S_SD: U4.11 (IO18); also elsewhere on the board
I2S_WS: U4.10 (IO17); also elsewhere on the board
LED1 Signal: U4.4 (IO4); also elsewhere on the board
LED2 Signal: U4.5 (IO5); also elsewhere on the board
LED3 Signal: U4.6 (IO6); also elsewhere on the board
LED4 Signal: U4.7 (IO7); also elsewhere on the board
Motor Power: J12.2; also elsewhere on the board
Motor Signal: R26.1, U4.8 (IO15); also elsewhere on the board
unnamed 26: 3.3V1.2 (A), R21.2; also elsewhere on the board
unnamed 27: 5V1.2 (A), R20.2; also elsewhere on the board
unnamed: C8.1, C9.1, D2.1 (K), D3.1 (K), R20.1, U5.1 (VIN), U5.3 (EN)
unnamed: D3.2 (A), FB1.2
unnamed: MOTOR1.2 (A), R26.2
unnamed 45: R23.2, SW3.2 (A); also elsewhere on the board
unnamed: C21.1, R18.2, SW1.2, U4.3 (EN)
unnamed: R19.2, SW2.1, U4.27 (IO0)
unnamed: U4.14 (USB_D+/IO20), U6.3 (I/O2)
unnamed: U4.13 (USB_D-/IO19), U6.1 (I/O1)
unnamed 57: R22.2, USB1.2 (A); also elsewhere on the board
RS485_DE: U4.35 (MTMS/IO42); also elsewhere on the board
RS485_RX: U4.38 (IO2); also elsewhere on the board
RS485_TX: U4.39 (IO1); also elsewhere on the board

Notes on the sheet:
Expansion Header for future use


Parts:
C8, C21: 1uF
C20: 0.1uF
C22: 22uF
D2: SS14
D4, D5, D6, D7: LED
J8: USB_C_Receptacle
R16, R17: 5.1k
R18, R19: 10k
R20, R22: 1.5k
R21, R23: 680
SW1, SW2: SW_Push
U4: ESP32-S3-WROOM-1; ESP32-S3-WROOM-2
U5: AP2112K-3.3; SOT-23-5
U6: USBLC6-2SC6; SOT-23-6

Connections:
+3V3: C20.1, C22.1, R18.1, R19.1, R21.1, U4.2 (3V3), U5.5 (VOUT); also elsewhere on the board
/ESP32/A6: J8.A6 (D+), J8.B6 (D+), U6.4 (I/O2)
/ESP32/A7: J8.A7 (D-), J8.B7 (D-), U6.6 (I/O1)
/ESP32/GPIO8: U4.12 (IO8); also elsewhere on the board
/ESP32/GPIO9: U4.17 (IO9); also elsewhere on the board
/ESP32/GPIO10: U4.18 (IO10); also elsewhere on the board
/ESP32/GPIO11: U4.19 (IO11); also elsewhere on the board
/ESP32/GPIO12: U4.20 (IO12); also elsewhere on the board
/ESP32/GPIO13: U4.21 (IO13); also elsewhere on the board
/ESP32/GPIO14: U4.22 (IO14); also elsewhere on the board
/ESP32/GPIO21: U4.23 (IO21); also elsewhere on the board
/ESP32/SW_LED: R23.1, U4.25 (IO48)
/ESP32/VBUS: D2.2 (A), J8.A4 (VBUS), J8.A9 (VBUS), J8.B4 (VBUS), J8.B9 (VBUS), R22.1, U6.5 (VBUS)
GND1: C8.2, C20.2, C21.2, C22.2, D4.1 (K), D5.1 (K), D6.1 (K), D7.1 (K), J8.A1 (GND), J8.A12 (GND), J8.B1 (GND), J8.B12 (GND), R16.2, R17.2, SW1.1, SW2.2, U4.1 (GND), U4.40 (GND), U4.41 (GND), U5.2 (GND), U6.2 (GND); also elsewhere on the board
I2S_SCK: U4.9 (IO16); also elsewhere on the board
I2S_SD: U4.11 (IO18); also elsewhere on the board
I2S_WS: U4.10 (IO17); also elsewhere on the board
LED1 Signal: U4.4 (IO4); also elsewhere on the board
LED2 Signal: U4.5 (IO5); also elsewhere on the board
LED3 Signal: U4.6 (IO6); also elsewhere on the board
LED4 Signal: U4.7 (IO7); also elsewhere on the board
Motor Signal: U4.8 (IO15); also elsewhere on the board
unnamed 26: D5.2 (A), R21.2; also elsewhere on the board
unnamed 27: D4.2 (A), R20.2; also elsewhere on the board
unnamed 28: C8.1, D2.1 (K), R20.1, U5.1 (VIN), U5.3 (EN); also elsewhere on the board
unnamed 45: D7.2 (A), R23.2; also elsewhere on the board
unnamed: C21.1, R18.2, SW1.2, U4.3 (EN)
unnamed: R19.2, SW2.1, U4.27 (IO0)
unnamed: U4.14 (USB_D+/IO20), U6.3 (I/O2)
unnamed: U4.13 (USB_D-/IO19), U6.1 (I/O1)
unnamed 57: D6.2 (A), R22.2; also elsewhere on the board
RS485_DE: U4.35 (MTMS/IO42); also elsewhere on the board
RS485_RX: U4.38 (IO2); also elsewhere on the board
RS485_TX: U4.39 (IO1); also elsewhere on the board


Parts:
C14, C15: 10uF 25v; C_1206_3216Metric_Pad1.33x1.80mm_HandSolder
C16: 0.1uF; C_1206_3216Metric_Pad1.33x1.80mm_HandSolder
C17, C18: 22uF; C_1210_3225Metric_Pad1.33x2.70mm_HandSolder
J6, J7: Conn_01x02_Pin; JST_XH_B2B-XH-AM_1x02_P2.50mm_Vertical
L2: 3.3uH; IND_SPM6530T-3R3M; PARTREV N/A; LCSC C76856
R13: 35.7k; R_1206_3216Metric_Pad1.30x1.75mm_HandSolder
R14: 10k; R_1206_3216Metric_Pad1.30x1.75mm_HandSolder
R15: 100k; R_1206_3216Metric_Pad1.30x1.75mm_HandSolder
U3: TPS563201DDCR; TSOT-23-6_HandSoldering; PARTREV December 2015; LCSC C116592

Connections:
GND1: C14.2, C15.2, C17.2, C18.2, J6.1, J7.1, R14.2, R15.2, U3.1 (GND); also elsewhere on the board
Motor Power: C14.1, C15.1, U3.3 (VIN); also elsewhere on the board
Motor Signal: R15.1, U3.5 (EN); also elsewhere on the board
unnamed: C17.1, C18.1, J6.2, J7.2, L2.2, R13.1
unnamed: C16.1, L2.1, U3.2 (SW)
unnamed: C16.2, U3.6 (VBST)
unnamed: R13.2, R14.1, U3.4 (VFB)


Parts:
C23, C24: 0.1uF; C_1206_3216Metric_Pad1.33x1.80mm_HandSolder
C25: 4.7uF; C_1206_3216Metric_Pad1.33x1.80mm_HandSolder
J10: Conn_01x04_Pin; JST_XH_B2B-XH-AM_1x02_P2.50mm_Vertical
J11: Conn_01x08_Pin; JST_XH_B8B-XH-AM_1x08_P2.50mm_Vertical
R24, R29: 100k; R_1206_3216Metric_Pad1.30x1.75mm_HandSolder
R25: 120; R_1206_3216Metric_Pad1.30x1.75mm_HandSolder
R27, R28: 33; R_1206_3216Metric_Pad1.30x1.75mm_HandSolder
U7: THVD1400D; SOIC-8_3.9x4.9mm_P1.27mm; LCSC C3235232
U8: SM712; SOT23-WIDE; LCSC C502564

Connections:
+3V3: C23.1, C24.1, C25.1, J11.1, U7.8 (VCC); also elsewhere on the board
GND1: C23.2, C24.2, C25.2, J11.2, J11.4, J11.6, J11.8, R24.2, R29.2, U7.5 (GND), U8.3; also elsewhere on the board
I2S_SCK: R27.2; also elsewhere on the board
I2S_SD: J11.7, R29.1; also elsewhere on the board
I2S_WS: R28.2; also elsewhere on the board
unnamed: J10.1, R25.2, U7.7 (B), U8.1
unnamed: J10.2, R25.1, U7.6 (A), U8.2
unnamed: J11.3, R27.1
unnamed: J11.5, R28.1
RS485_DE: R24.1, U7.2 (~RE), U7.3 (DE); also elsewhere on the board
RS485_RX: U7.1 (RO); also elsewhere on the board
RS485_TX: U7.4 (DI); also elsewhere on the board

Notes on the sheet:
RS485 Transceiver
INMP441 Module Header
INMP441 Module will be on an 8-10 inch lead from the PCB Connected with CAT5 twisted pair. Ground/Signal for each twisted pair.

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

Board: 4 copper layers, 72.0 x 66.0 mm, 85 parts (0 on the bottom side), 63 nets.

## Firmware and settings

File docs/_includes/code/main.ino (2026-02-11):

/*
  Sensor-controlled motors + RUN/PAUSE state machine

  Pins:
    Button: D13 (active-low, INPUT_PULLUP)
    Ultrasonic: TRIG=D11, ECHO=D12
    SG90 Servo: D10
    Stepper (28BYJ-48 + ULN2003): D4-D7 (wired to IN1..IN4)

  DC motor via L293D:
    ENA = D9 (PWM)
    IN1 = D8
    IN2 = D3
*/

#include <Wire.h>
#include <MPU9250_asukiaaa.h>
#include <Servo.h>
#include <Stepper.h>
#include <math.h>

#ifndef M_PI
#define M_PI 3.14159265358979323846
#endif

// ---------------------- Pins ----------------------
const int POT_PIN = A0;

// Ultrasonic
const int TRIG_PIN = 11;
const int ECHO_PIN = 12;

// Servo
const int SERVO_PIN = 10;

// Button
const int BUTTON_PIN = 13; // active-low

// Stepper pins D4-D7 wired to ULN2003 IN1..IN4
const int STEPPER_D4_IN1 = 4;
const int STEPPER_D5_IN2 = 5;
const int STEPPER_D6_IN3 = 6;
const int STEPPER_D7_IN4 = 7;

// DC motor pins with L293
const int DC_MOTOR_ENA_PWM = 9; // ENA (PWM)
const int DC_MOTOR_IN1     = 8; // IN1 (direction)
const int DC_MOTOR_IN2     = 3; // IN2 (direction)

// ---------------------- Timing ----------------------
const unsigned long POT_PERIOD_MS = 30;
const unsigned long US_PERIOD_MS  = 100;
const unsigned long IMU_PERIOD_MS = 30;

const unsigned long DEBOUNCE_MS   = 35;

// ---------------------- Servo control ----------------------
Servo servo;
const int SERVO_MIN_ANGLE = 10;
const int SERVO_MAX_ANGLE = 180;
int servoAngleCmd = SERVO_MIN_ANGLE;

// ---------------------- Stepper control ----------------------
const int stepsPerRevolution = 2048;
Stepper myStepper(
  stepsPerRevolution,
  STEPPER_D4_IN1,
  STEPPER_D6_IN3,
  STEPPER_D5_IN2,
  STEPPER_D7_IN4
);

const long STEPPER_POS_LIMIT = stepsPerRevolution / 4;
const int  STEPPER_MAX_STEP_PER_UPDATE = 6;
long stepperPos = 0;
long stepperTargetPos = 0;

// ---------------------- DC motor control ----------------------
int  dcSpeedCmd = 0;
int  lastPrintedDcSpeed = -1;

// ---------------------- MPU9250 ----------------------
MPU9250_asukiaaa imu;

// ---------------------- State machine ----------------------
bool motorsRunning = true;

// Debounce variables
int buttonStable = HIGH;
int buttonLastRead = HIGH;
unsigned long lastDebounceMs = 0;

// ---------------------- Sensor/report timers ----------------------
unsigned long lastPotMs = 0;
unsigned long lastUsMs  = 0;
unsigned long lastImuMs = 0;

float lastUsCm = NAN;

// ---------------------- Helpers ----------------------
float readUltrasonicCm() {
  digitalWrite(TRIG_PIN, LOW);
  delayMicroseconds(2);
  digitalWrite(TRIG_PIN, HIGH);
  delayMicroseconds(10);
  digitalWrite(TRIG_PIN, LOW);

  unsigned long duration = pulseIn(ECHO_PIN, HIGH, 30000UL);
  if (duration == 0) return NAN;

  return (duration * 0.0343f) / 2.0f;
}

int potToServoAngle(int pot) {
  long a = map(pot, 0, 1023, SERVO_MIN_ANGLE, SERVO_MAX_ANGLE);
  if (a < SERVO_MIN_ANGLE) a = SERVO_MIN_ANGLE;
  if (a > SERVO_MAX_ANGLE) a = SERVO_MAX_ANGLE;
  return (int)a;
}

void handleButton(unsigned long now) {
  int raw = digitalRead(BUTTON_PIN);

  if (raw != buttonLastRead) {
    buttonLastRead = raw;
    lastDebounceMs = now;
  }

  if ((now - lastDebounceMs) >= DEBOUNCE_MS && raw != buttonStable) {
    buttonStable = raw;

    if (buttonStable == LOW) {
      motorsRunning = !motorsRunning;
      Serial.print(F("BUTTON,pressed,STATE,"));
      Serial.println(motorsRunning ? F("RUN") : F("PAUSE"));
    }
  }
}

// ---------------------- L293D MOTOR FUNCTIONS ----------------------
void dcMotorClockwise(int speed) {
  digitalWrite(DC_MOTOR_IN1, HIGH);
  digitalWrite(DC_MOTOR_IN2, LOW);
  analogWrite(DC_MOTOR_ENA_PWM, speed);
}

void dcMotorStop() {
  analogWrite(DC_MOTOR_ENA_PWM, 0);
  digitalWrite(DC_MOTOR_IN1, LOW);
  digitalWrite(DC_MOTOR_IN2, LOW);
}

int ultrasonicToDcSpeed(float cm) {
  const float MIN_CM = 2.0f;
  const float MAX_CM = 400.0f;

  if (isnan(cm)) return 255;

  if (cm <= MIN_CM) return 0;
  if (cm >= MAX_CM) return 255;

  float t = (cm - MIN_CM) / (MAX_CM - MIN_CM);
  int s = (int)lroundf(t * 255.0f);
  if (s < 0) s = 0;
  if (s > 255) s = 255;
  return s;
}

void updateDcMotorFromUltrasonic(unsigned long now) {
  dcSpeedCmd = ultrasonicToDcSpeed(lastUsCm);

  if (dcSpeedCmd <= 0) {
    dcMotorStop();
  } else {
    dcMotorClockwise(dcSpeedCmd);
  }

  if (dcSpeedCmd != lastPrintedDcSpeed) {
    lastPrintedDcSpeed = dcSpeedCmd;

    Serial.print(F("DCM,speed,"));
    Serial.print(dcSpeedCmd);
    Serial.print(F(",dir,CW"));
    Serial.print(F(",MOTORS,"));
    Serial.println(motorsRunning ? F("RUN") : F("PAUSE"));
  }
}

// ---------------------- Motor + Sensor Updates ----------------------
void updateMotorsFromSensors(int pot, float pitchDeg) {
  servoAngleCmd = potToServoAngle(pot);
  servo.write(servoAngleCmd);

  const float PITCH_LIMIT_DEG = 45.0f;
  if (pitchDeg >  PITCH_LIMIT_DEG) pitchDeg =  PITCH_LIMIT_DEG;
  if (pitchDeg < -PITCH_LIMIT_DEG) pitchDeg = -PITCH_LIMIT_DEG;

  stepperTargetPos = (long)(pitchDeg * (float)STEPPER_POS_LIMIT / PITCH_LIMIT_DEG);

  long err = stepperTargetPos - stepperPos;
  if (err != 0) {
    int stepCmd = (int)err;
    if (stepCmd >  STEPPER_MAX_STEP_PER_UPDATE) stepCmd =  STEPPER_MAX_STEP_PER_UPDATE;
    if (stepCmd < -STEPPER_MAX_STEP_PER_UPDATE) stepCmd = -STEPPER_MAX_STEP_PER_UPDATE;

    long absErr = labs(err);
    int rpm = 4;
    if (absErr > (STEPPER_POS_LIMIT / 2)) rpm = 12;
    else if (absErr > (STEPPER_POS_LIMIT / 4)) rpm = 9;
    else if (absErr > 40) rpm = 6;

    myStepper.setSpeed(rpm);
    myStepper.step(stepCmd);
    stepperPos += stepCmd;
  }
}

void updateUltrasonic(unsigned long now) {
  if (now - lastUsMs < US_PERIOD_MS) return;
  lastUsMs = now;

  lastUsCm = readUltrasonicCm();

  Serial.print(F("US_CM,"));
  if (isnan(lastUsCm)) Serial.println(F("nan"));
  else Serial.println(lastUsCm, 1);
}

void reportPot(unsigned long now, int pot) {
  if (now - lastPotMs < POT_PERIOD_MS) return;
  lastPotMs = now;

  Serial.print(F("POT,"));
  Serial.print(pot);
  Serial.print(F(",SERVO_CMD,"));
  Serial.print(servoAngleCmd);
  Serial.print(F(",MOTORS,"));
  Serial.println(motorsRunning ? F("RUN") : F("PAUSE"));
}

void reportImu(unsigned long now,
               float ax, float ay, float az,
               float gx, float gy, float gz,
               int mx, int my, int mz,
               float pitchDeg) {
  if (now - lastImuMs < IMU_PERIOD_MS) return;
  lastImuMs = now;

  Serial.print(F("IMU,"));
  Serial.print(ax, 4); Serial.print(',');
  Serial.print(ay, 4); Serial.print(',');
  Serial.print(az, 4); Serial.print(',');
  Serial.print(gx, 4); Serial.print(',');
  Serial.print(gy, 4); Serial.print(',');
  Serial.print(gz, 4); Serial.print(',');
  Serial.print(mx); Serial.print(',');
  Serial.print(my); Serial.print(',');
  Serial.print(mz);

  Serial.print(F(",PITCH_DEG,"));
  Serial.print(pitchDeg, 2);

  Serial.print(F(",STEPPER_TGT,"));
  Serial.print(stepperTargetPos);
  Serial.print(F(",STEPPER_POS,"));
  Serial.print(stepperPos);

  Serial.print(F(",DCM_SPEED,"));
  Serial.print(dcSpeedCmd);
  Serial.print(F(",DCM_DIR,CW"));
}

void setup() {
  Serial.begin(115200);

  pinMode(TRIG_PIN, OUTPUT);
  pinMode(ECHO_PIN, INPUT);

  pinMode(BUTTON_PIN, INPUT_PULLUP);

  // DC motor pins (L293)
  pinMode(DC_MOTOR_ENA_PWM, OUTPUT);
  pinMode(DC_MOTOR_IN1, OUTPUT);
  pinMode(DC_MOTOR_IN2, OUTPUT);
  dcMotorStop();

  // Servo
  servo.attach(SERVO_PIN);
  servo.write(servoAngleCmd);

  // IMU
  Wire.begin();
  imu.setWire(&Wire);
  imu.beginAccel();
  imu.beginGyro();
  imu.beginMag();

  // Stepper baseline
  myStepper.setSpeed(6);

  Serial.println(F("BOOT,servo=pot stepper=imu dc=ultrasound button=run_pause"));
  Serial.println(F("PINS,btn=13 trig=11 echo=12 servo=10 stepper=4-7 dc_l293: ena=9 in1=8 in2=3"));
  Serial.println(F("STATE,RUN"));
}

void loop() {
  unsigned long now = millis();

  handleButton(now);

  int pot = analogRead(POT_PIN);
  updateUltrasonic(now);

  imu.accelUpdate();
  imu.gyroUpdate();
  int magResult = imu.magUpdate();
  if (magResult != 0) {
    imu.beginMag();
    imu.magUpdate();
  }

  float ax = imu.accelX();
  float ay = imu.accelY();
  float az = imu.accelZ();

  float gx = imu.gyroX();
  float gy = imu.gyroY();
  float gz = imu.gyroZ();

  int mx = imu.magX();
  int my = imu.magY();
  int mz = imu.magZ();

  float pitchDeg = atan2f(-ax, sqrtf(ay * ay + az * az)) * 180.0f / (float)M_PI;

  if (motorsRunning) {
    updateMotorsFromSensors(pot, pitchDeg);
    updateDcMotorFromUltrasonic(now);
  }

  reportPot(now, pot);
  reportImu(now, ax, ay, az, gx, gy, gz, mx, my, mz, pitchDeg);
}

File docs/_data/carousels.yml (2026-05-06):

home_hero:
  aria_label: Robot highlights
  autoplay_ms: 5000
  slides:
  - type: image
    src: /assets/img/angled_final_cover.JPG
    alt: Final hexapod, angled view
    caption: Final Robot, Angled View
    loading: eager
    pending: false
  - type: animation
    src: /assets/videos/walking_outside2.webm
    alt: Second final robot walking run outdoors
    caption: Final Walking Demonstration II
    loading: lazy
    pending: false
  - type: image
    src: /assets/hardware/full_assembly_no_lid.jpg
    alt: Full robot assembly with lid removed
    caption: Final Assembly Without Lid
    loading: lazy
    pending: false
  - type: image
    src: /assets/hardware/chassis_and_early_board.jpg
    alt: Chassis and early board during robot integration
    caption: Chassis and Early Board Integration
    loading: lazy
    pending: false
  - type: animation
    src: /assets/videos/unloaded_all_legs_motion.webm
    alt: Six legs moving unloaded during final bring-up
    caption: Unloaded Six-Leg Motion
    loading: lazy
    pending: false
  - type: image
    src: /assets/software/orbslam_and_ogm_and_robot_visual.jpg
    alt: ORB-SLAM, occupancy-grid map, and robot visualization
    caption: ORB-SLAM, OGM, and Robot Visualization
    loading: lazy
    pending: false
  - type: image
    src: /assets/img/linkage_MK1.gif
    alt: First iteration linkage
    caption: Early Linkage Prototype
    loading: lazy
  - type: animation
    src: /assets/img/cpg_humanoid.webm
    alt: CPG gait with humanoid rider demonstration
    caption: Early CPG with Humanoid Rider
    loading: lazy
lab_highlights:
  aria_label: Motors/Sensors lab highlights
  autoplay_ms: 5000
  slides:
  - type: image
    src: /assets/img/lab-1.jpg
    alt: Lab highlight photo 1
    caption: Sensors lab setup
    loading: eager
  - type: image
    src: /assets/img/lab-2.jpg
    alt: Lab highlight photo 2
    caption: Motors lab setup
    loading: lazy
  - type: image
    src: /assets/img/lab-3.gif
    alt: Lab highlight GIF
    caption: Bring-up motion test
    loading: lazy
overall_assembly_evolution:
  aria_label: Overall assembly CAD evolution
  autoplay_ms: 0
  slides:
  - type: iframe
    url: https://andrew3535.autodesk360.com/shares/public/SH90d2dQT28d5b602811d4ad9f04a672e4a9?mode=embed
    use_fallback: false
    fallback_src: /assets/designs/v5_final_assembly.glb
    fallback_type: model
    fallback_label: Open local v5 GLB fallback
    alt: Final v5 full hexapod assembly in Fusion 360
    caption: "Final v5 full assembly \u2014 Fusion 360 primary view with local GLB fallback"
    pending: false
  - type: model
    src: /assets/designs/hexapod-v1.glb
    alt: Version 1 overall assembly local GLB
    caption: "Version 1 assembly \u2014 local GLB viewer"
    pending: false
  - type: iframe
    url: https://andrew3535.autodesk360.com/shares/public/SH90d2dQT28d5b6028115eddcfc090724d85?mode=embed
    use_fallback: false
    fallback_src: /assets/designs/hexapod-v2.glb
    fallback_type: model
    fallback_label: Open local v2 GLB fallback
    alt: Version 2 overall assembly in Fusion 360
    caption: "Version 2 assembly \u2014 Fusion 360 primary view with local GLB fallback"
    pending: false
  - type: iframe
    url: https://andrew3535.autodesk360.com/shares/public/SH90d2dQT28d5b6028113353606288e33908?mode=embed
    use_fallback: false
    fallback_src: /assets/designs/hexapod-v3.glb
    fallback_type: model
    fallback_label: Open local v3 GLB fallback
    alt: Version 3 overall assembly in Fusion 360
    caption: "Version 3 assembly \u2014 Fusion 360 primary view with local GLB fallback"
    pending: false
  - type: iframe
    url: https://andrew3535.autodesk360.com/shares/public/SH90d2dQT28d5b602811e0782a2169d822e3?mode=embed
    use_fallback: false
    fallback_src: /assets/designs/hexapod-v4.glb
    fallback_type: model
    fallback_label: Open local v4 GLB fallback
    alt: Version 4 overall assembly in Fusion 360
    caption: "Version 4 assembly \u2014 Fusion 360 primary view with local GLB fallback"
    pending: false
simulation_validation:
  aria_label: Simulation validation media
  autoplay_ms: 5500
  slides:
  - type: animation
    src: /assets/software/mujoco_first_linkage_test.webm
    alt: First MuJoCo linkage test animation
    caption: First MuJoCo linkage test
    loading: eager
    pending: false
  - type: animation
    src: /assets/img/cpg_humanoid.webm
    alt: Untuned CPG gait simulation animation
    caption: Untuned CPG phase/gait experiment
    loading: lazy
    pending: false
  - type: animation
    src: /assets/software/mujoco_all_linkages_running.webm
    alt: All six linkages running in MuJoCo
    caption: All linkages running in MuJoCo
    loading: lazy
    pending: false
  - type: animation
    src: /assets/software/mujoco_support_wheel_test.webm
    alt: MuJoCo support wheel stability test animation
    caption: Support wheel stability test
    loading: lazy
    pending: false
  - type: animation
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

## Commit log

2026-01-29 initial template
    [issues_log.csv, parts_list.csv]
2026-02-10 Create motors-sensors-lab
2026-02-10 Update motors-sensors-lab
2026-02-25 upload latest schematic version
    [01_battery_protection.kicad_sch, 02_motor_distribution.kicad_sch, 03_DCDC_5V_3.3V.kicad_sch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]
2026-02-28 Expand implementation documentation with new sections
    Added sections for chassis assembly, leg fabrication, compute & sensing, power system, software interface, local controller, SLAM, ESP32, and simulation.
